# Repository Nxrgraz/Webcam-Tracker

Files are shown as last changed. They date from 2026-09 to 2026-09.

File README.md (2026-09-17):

# AI Pan Tilt Face Tracker

A real time two axis vision tracking system that detects and follows a specific face using a custom YOLO model, C++, OpenCV, model predictive control, and Arduino controlled pan and tilt servos.
## Demo

[Watch the full face tracking demo](demo/tracker_demo.mp4)

The system combines computer vision, target motion estimation, feedback control, and embedded hardware to keep a detected face near the center of the camera frame while reducing overshoot, jitter, and unnecessary servo movement.

## Overview

A webcam continuously captures video while a custom YOLO ONNX model detects the target face.

The software measures the target's position relative to the center of the image and estimates its movement across the frame. Independent predictive controllers for the pan and tilt axes then determine how the camera should move.

Instead of reacting only to the current image error, the controller predicts how the target and camera are expected to move over the next several control steps.

The resulting commands are transmitted over serial to an Arduino controlling the two servo motors.

## System Pipeline

```text
Webcam
   |
   v
Camera Frame
   |
   v
Image Preprocessing and Letterboxing
   |
   v
Custom YOLO Face Detector
   |
   v
Non Maximum Suppression
   |
   v
Target Selection and Tracking
   |
   v
Face Position Smoothing
   |
   v
Image Error Calculation
   |
   v
Target Motion Observer
   |
   +----------------------+
   |                      |
   v                      v
Target Velocity      Servo Motion Model
   |                      |
   +-----------+----------+
               |
               v
       Future Motion Prediction
               |
        +------+------+
        |             |
        v             v
     Pan MPC       Tilt MPC
        |             |
        +------+------+
               |
               v
     Velocity and Acceleration
             Limits
               |
               v
       Servo Angle Commands
               |
               v
            Arduino
          /         \
         v           v
    Pan Servo    Tilt Servo
```

## Features

### Custom Face Detection

The tracker uses a custom YOLO model exported to ONNX and executed through OpenCV DNN.

The detector runs on a letterboxed 640 × 640 image while preserving the original camera aspect ratio.

Detections below the confidence threshold are rejected and Non Maximum Suppression is used to remove overlapping detections.

### Target Association

When tracking begins, the highest confidence detection is selected.

Once a target has been established, subsequent detections are compared with the previous smoothed target position. The closest detection is selected to reduce unnecessary switching between detected objects.

### Target Position Smoothing

Raw bounding box positions from the detector can change slightly even when the target is stationary.

An exponential smoothing filter is applied to the detected face center before the position is used by the controller.

This reduces camera movement caused by small detection fluctuations.

### Predictive Motion Estimation

The tracker estimates the image velocity of the target from consecutive measurements.

The observer also estimates how much apparent image motion is being produced by movement of the camera itself.

Conceptually,

```text
Target Image Velocity =
Observed Image Velocity
-
Camera Induced Image Velocity
```

This helps distinguish actual target motion from image movement caused by the pan and tilt servos.

### Model Predictive Control

Automatic tracking uses independent predictive controllers for the pan and tilt axes.

For each control cycle, the controller evaluates a range of possible servo velocity commands and simulates their effect over a future prediction horizon.

Each candidate command is scored using a cost function that considers

```text
Tracking error
Control effort
Change in control command
Terminal tracking error
```

The command producing the lowest predicted cost is selected.

This allows the system to react not only to where the target currently is, but also to where it is moving.

### Servo Dynamics Model

The predictive controller contains a simplified first order model of each servo axis.

The model includes

```text
Servo response time
Command gain
Estimated control delay
Pixels of image movement per degree of camera rotation
Maximum servo velocity
Maximum servo acceleration
```

Pan and tilt are modeled separately because the mechanical response of the two axes is different.

The current model parameters are initial estimates and are intended to be refined using experimental measurements.

### Delay Compensation

Camera processing, neural network inference, serial communication, and servo movement introduce delay.

The controller maintains a queue of previous commands to approximate this delay when predicting future system behavior.

This prevents the controller from assuming that a newly issued servo command affects the camera immediately.

### Predictive Tracking Activation

Tracking does not depend only on position error.

The system also considers estimated target velocity.

If a target begins moving quickly, tracking can activate before the target moves far from the center of the image.

This improves response to moving targets compared with a purely position based dead zone.

### Tracking Hysteresis

Different thresholds are used for starting and stopping movement.

For example, the pan axis requires a larger error to begin tracking than it requires to stop tracking.

This prevents rapid switching between moving and stopping when the target is close to the center of the frame.

### Stationary Hold

When the target remains close to the image center and nearly motionless for several consecutive control cycles, the tracker enters a stationary hold state.

During stationary hold

```text
Pan velocity is set to zero
Tilt velocity is set to zero
Predictive velocity states are reset
Servo targets are synchronized with the physical servo commands
```

The hold is released immediately when the target moves far enough or fast enough.

This reduces continuous servo hunting caused by small camera and detector fluctuations.

### Motion Constraints

Servo motion is limited by both velocity and acceleration constraints.

Current software limits are approximately

```text
Maximum velocity:      18 degrees per second
Maximum acceleration:  45 degrees per second squared
```

These limits help produce smoother physical movement and prevent aggressive controller commands.

### Servo Safety Limits

Software limits prevent the mechanism from commanding unsafe angles.

```text
Pan:   15 to 165 degrees
Tilt:  60 to 120 degrees
```

### Target Loss Handling

When the face is temporarily lost, servo velocities are gradually reduced instead of stopping abruptly.

After the target has been missing for several frames, the tracking and prediction states are reset.

This prevents stale target information from affecting the next detection.

### Manual Control

The tracker can be switched between automatic MPC tracking and manual control.

```text
M     Toggle automatic and manual mode

W     Tilt camera up
S     Tilt camera down
A     Pan camera left
D     Pan camera right

R     Smoothly return both axes to center

Q     Quit
ESC   Quit
```

### Smooth Center Reset

Pressing `R` disables automatic tracking and gradually returns both axes to

```text
Pan:  90 degrees
Tilt: 90 degrees
```

rather than immediately snapping the servos to their center positions.

## Visual Debugging

The OpenCV display includes

```text
Detected face bounding box
Detection confidence
Raw face center
Smoothed face center
Camera frame center
Tracking dead zone
Predicted future target position
Current pan angle
Current tilt angle
Number of detections
Current operating mode
```

The predicted target location is displayed separately from the current target location so the motion observer can be inspected visually.

## Controller Debug Output

The application also prints controller information to the terminal, including

```text
Pan target angle
Pan angle sent to Arduino
Tilt target angle
Tilt angle sent to Arduino
Horizontal image error
Vertical image error
Estimated target velocity
Estimated camera velocity
MPC pan command
MPC tilt command
Stationary hold status
```

This information can be recorded during testing and used to tune the predictive model.

## Hardware

The system is designed around

```text
Webcam
Arduino
Two axis pan tilt mechanism
Two servo motors
Computer running the C++ vision and control application
```

The computer performs neural network inference and predictive control while the Arduino receives pan and tilt angle commands and drives the physical servos.

## Software

The project uses

```text
C++
OpenCV
OpenCV DNN
ONNX
YOLO
Serial communication
Arduino
Model Predictive Control
```

## Communication

The computer communicates with the Arduino through a serial connection at

```text
115200 baud
```

Servo commands are transmitted using the format

```text
panAngle,tiltAngle
```

For example

```text
92.35,87.72
```

The controller avoids transmitting another command when both servo angles have changed by less than a small threshold.

## Current Control Configuration

The controller currently runs at approximately 20 Hz.

The MPC prediction horizon contains 10 control steps, corresponding to roughly 0.5 seconds of predicted motion.

Pan and tilt use separate dynamic models and delay estimates.

These values are currently starting estimates rather than experimentally identified plant parameters.

## Current Development Direction

The next major control improvement is experimental system identification.

Future testing can be used to measure

```text
Actual servo response time
Pan and tilt command delay
Pixels per degree of camera movement
Servo command gain
Response differences across servo angles
```

These measurements can then replace the initial model estimates used by the predictive controller.

Additional future improvements include

```text
Automatic controller parameter identification
Performance logging and plotting
Quantitative tracking error evaluation
Improved target reacquisition
Hardware specific servo calibration
Higher performance inference
More advanced coupled pan and tilt control
```

## Project Goal

The goal of this project is not simply to move a webcam toward a detected face.

It is to explore how computer vision, machine learning, state estimation, feedback control, and embedded hardware can be integrated into a complete real time robotic tracking system.

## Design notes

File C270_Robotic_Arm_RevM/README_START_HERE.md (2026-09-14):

# C270 robotic arm Revision M

Revision M enlarges the cap opening to **27 × 15 mm**, provides direct access to the original servo shaft screws, and turns the webcam mount so the upper servo aims the camera up and down. The arm is now 10 mm thick to reduce sideways flex.

**Print three updated parts: the arm, cap, and webcam cradle. Reuse the Revision L base.** The base STL in this package is unchanged. Revision M cap holes use a new **34 × 17 mm** pattern and require the matching Revision M arm.

| File in Printable_Parts | Quantity | Action |
| --- | --- | --- |
| CurvedArm_SG90_TiltHolder.stl | 1 | Print the new thicker arm with screw access and cable tie tabs |
| SG90_RetainingCap.stl | 1 | Print the 27 × 15 mm opening and matching screw pattern |
| Logitech_C270_ScrewlessCradle.stl | 1 | Print the new side-mounted cradle for actual camera tilt |
| PanServo_StabilityBase.stl | 1 total | Reuse your existing Revision L base |

Print individual STLs. The STEP assemblies show placement and can be imported into SolidWorks; they are not files to print as a single object. The servos and camera in the full assembly are visualization references.

## Stability requirement

**Secure the gray base to a rigid work surface using its four M4 mounting holes.** The analysis does not support claiming that the lightweight base will resist cable pull while free-standing. The revised arm is stiffer, but printed-part flex, servo backlash and shaft-bearing compliance still require a physical check.

## Read before assembly

- `Documentation/Assembly_and_Printing_Guide.md` explains the screws, assembly order and what to print.
- `Documentation/Wiring_and_Motion.md` explains both USB connections, servo power, cable slack and travel limits.
- `Documentation/Engineering_Check.md` gives the assumptions, torque calculation and tipping calculation.
- `Documentation/CAD_and_Engineering_Results.json` contains the computed measurements and individual check results.
- `Software/Camera_RevM.cpp` and `Camera_RevM.exe` provide a separate tracker build with narrower commands and slower outgoing motion. Read the wiring guide before using it; it has not been run against hardware.

The previous Word guides remain with their older revisions. This revision's guides supersede their cap, cradle, screw-access, axis and stability instructions.

## Main dimensions

- Rectangular cap opening: 27 × 15 mm; this adds 5 mm to the former 22 mm side.
- Cap outer face: 42 × 26 mm; face thickness: 3 mm. Ear retaining pads extend 2.6 mm behind that face.
- Cap holes: 2.4 mm clearance; centers: 34 × 17 mm. Holder pilots: 1.8 mm.
- Original shaft-screw access: 6.4 mm diameter in the arm and cradle.
- Printed horn-screw seats: 1.2 mm material thickness after recessing.
- Arm ribbon: 14 mm wide, 10 mm thick; nominal 80 mm end-center spacing.
- Tilt: rotation about the upper servo's Y shaft; modeled movement −45° to +45°.
- Pan: rotation about vertical Z. These are two independent aiming rotations.

The screw-access changes address the blocked shaft-screw path found in the model. Actual screw head size, thread and under-head length have not been measured from your hardware. Compare them with the fastener table before tightening.

## Rebuilding the CAD

The `Source` folder contains the generator and build/verification script. Install the dependencies in an isolated Python environment, then run `python build_verify_revM.py` from that folder. The script regenerates the CAD, previews and numerical results in this revision folder; the written guides are maintained separately. Generated STEP files contain solids rather than a native SolidWorks feature history.

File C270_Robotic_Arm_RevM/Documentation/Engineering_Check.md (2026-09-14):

# Revision M engineering check

The geometry supports two independent camera aiming rotations and provides access to the shaft screws. The tipping calculation requires the base to be anchored. These checks establish geometric clearance and stated load estimates; they do not establish the strength of an unknown print or servo clone.

## Geometry and movement

The camera looks along +X at neutral. The pan shaft is vertical Z and the tilt shaft is Y. For pan p and tilt t, the viewing direction is `(cos(p)cos(t), sin(p)cos(t), -sin(t))`. At tilt −45°, 0° and +45°, the vertical component is respectively +0.7071, 0 and −0.7071. The upper joint therefore changes camera elevation rather than rolling the image.

The CAD checks sample tilt every 5° from −45° to +45°, checking the cradle, camera, clip, rotating horn and a straight rear cable proxy against the fixed parts. Those checks pass. The minimum sampled camera/cradle-to-fixed clearance is about 2.17 mm. Rotation about Y preserves every point's Y coordinate, and the moving camera/cradle assembly has at least 2 mm of axial separation from the upper fixed parts. A separate radial bounding check keeps it above the base throughout the motion, providing clearance bounds between the sampled angles as well. The flexible cable loops and actual molded connectors are not represented by those bounds.

The cap opening is 27 × 15 mm. Moving its screws to 34 × 17 mm centers retains at least 2.3 mm of material between the opening and the hole edges using a conservative horizontal measurement. A 6 mm under-head cap screw crosses 3 mm of cap and engages 3 mm of holder pilot. The modeled pilot surroundings contain material over that engagement length.

The arm and cradle have 6.4 mm center access openings. Original shaft screws seat on the original servo horns, so printed material does not consume their reach. Separate recessed horn screw seats leave 1.2 mm of print. Actual screw threads, heads, lengths and horn hole positions must be checked against the hardware.

## Tilt holding torque

For a mass m at perpendicular radius r from the tilt shaft, the maximum gravitational torque is `m g r`. In the customary kg·cm servo unit, use mass in kilograms multiplied by radius in centimetres.

The camera plus fixed clip is assigned the supplied 75 g total mass. Rather than guessing its exact center of mass, the calculation allows that mass center anywhere inside the camera/clip CAD envelope. Its maximum radial distance from Y is 49.92 mm. Printed cradle mass uses its CAD volume and a maximum effective density of 1.27 g/cm³.

| Quantity | Result |
| --- | --- |
| Camera and cradle gravity bound | 0.381 kg·cm |
| Gravity allowance for motion, chosen factor | 1.5 × |
| Assumed residual cable drag | 0.20 N at a 60 mm radius |
| Cable torque | 0.122 kg·cm |
| Estimated combined design demand | 1.5 × 0.381 + 0.122 = **0.694 kg·cm** |
| TowerPro SG90 published stall torque at 4.8 V | 1.8 kg·cm |
| Published stall torque divided by estimated demand | 2.59 |

The 0.20 N cable drag and 1.5 motion multiplier are design assumptions, not measurements or a simulation of the actual acceleration. A snag or fast reversal can exceed them. The published stall rating is not a continuous operating rating or a guarantee of stiffness. Actual servo type, voltage, temperature, wear and gear backlash affect holding performance. Check the powered assembly for sag and heating; do not describe this estimate as a proof that the camera can never droop.

The original [TowerPro SG90 specification](https://towerpro.com.tw/product/sg90-7/) is the source for the 1.8 kg·cm stall figure. It is a reference for a genuine TowerPro unit, not identification of the supplied hardware.

## Base tipping

For component masses m_i and positions r_i, the combined center of mass is `r_COM = sum(m_i r_i) / sum(m_i)`. On a circular base, a gravity-only stability margin is `R - horizontal_distance(r_COM, base_center)`.

The printed-part analysis samples effective density from 0.434 to 1.27 g/cm³ independently for each part. This deliberately broad range spans a light print through a solid plastic part; it is not a conversion from the slicer's infill percentage. The camera center of mass is allowed anywhere in its full envelope. The servos are assigned 9 g each and the horns 2 g each. Component centers come from CAD, with each moving part transformed through the tilt range.

To account for the rounded bottom edge, usable base support radius is taken as 68 mm rather than the nominal 70 mm. The worst sampled combination gives:

| Quantity | Conservative sampled result |
| --- | --- |
| Total moving and fixed assembly mass | 154.20 g |
| Horizontal center-of-mass radius | 63.78 mm |
| Remaining edge margin | **4.22 mm** |
| Restoring moment `M = total_mass × g × margin` | **0.00638 N·m** |
| Horizontal force at 180 mm height that equals that restoring moment | **0.0355 N** |

This is an intentionally conservative corner-of-envelope case, not a prediction of the exact physical center of mass. It nevertheless shows why a blanket promise of free-standing stability would be unjustified. Even when a real sample is better balanced, a cable pull can dominate the small restoring moment.

**Fasten the base to a rigid work surface with all four M4 holes, and anchor the stationary cable bundle beside it.** The holes form a 70.711 mm square. Use suitable washers and nuts and confirm the printed recesses are sound. A 1 N horizontal pull at 180 mm height creates 0.18 N·m; allowing twice that moment corresponds to approximately 5.1 N of additional force across a 70.711 mm bolt-row spacing. This estimates the anchor reaction, not a certified allowable load for the print, washers or work surface. A lightweight loose board can tip with the assembly and is not equivalent to a secured work surface.

## Arm flex

The ribbon thickness increases from 6 to 10 mm while its nominal width remains 14 mm. For the same homogeneous material, weak-direction rectangular-section inertia is `I = b t³ / 12`:

- Previous nominal section: 252 mm⁴.
- Revised nominal section: 1166.7 mm⁴.
- Ratio: 4.63.

This is a section comparison, not a claim that the complete printed arm is exactly 4.63 times stiffer. Curvature, screw access cutouts, layer orientation, infill, local stress concentrations and joints change the real result. The calculation does not include servo shaft/bearing deflection or horn compliance. Anchoring prevents base movement; a load test is still needed to check arm and joint sag.

## Acceptance checks on the real assembly

Measure the relevant servo feature before printing the new cap. Weigh the printed parts and record the material and settings. With the base anchored, support the camera during initial power-up and test one axis at a time near neutral. Increase travel gradually, confirming there is no wire tension, rubbing, case movement or loss of level at neutral. Do not force an unpowered geared servo through its travel. Observe whether the powered camera sags or the servos heat up under sustained load. Confirm physical travel limits before tracking.

The supplied tracker build reduces commands to the logical range 45–135 and at most one degree per 33 ms. Those limits reduce commanded motion; they do not measure cable force, guarantee physical servo angle or prevent droop after power loss.

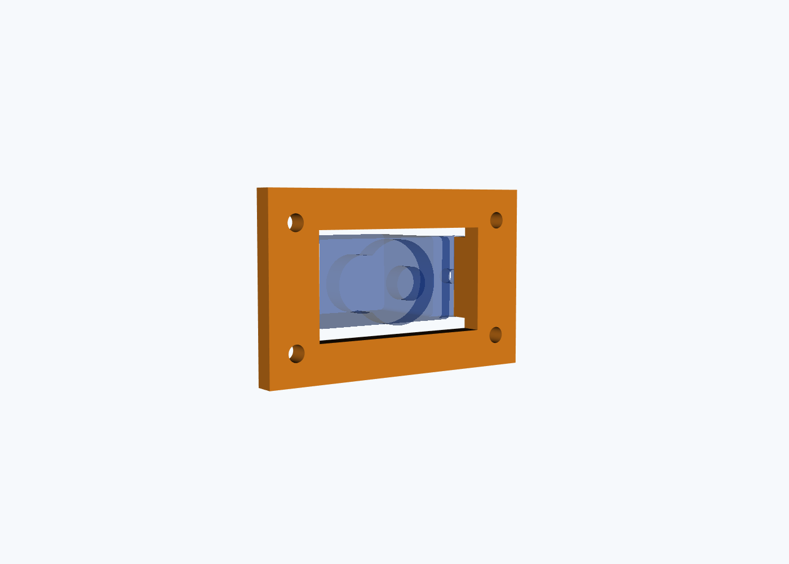
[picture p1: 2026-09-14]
C270_Robotic_Arm_RevM/Renders/07_SG90_RetainingCap_Rectangular_Clearance.png

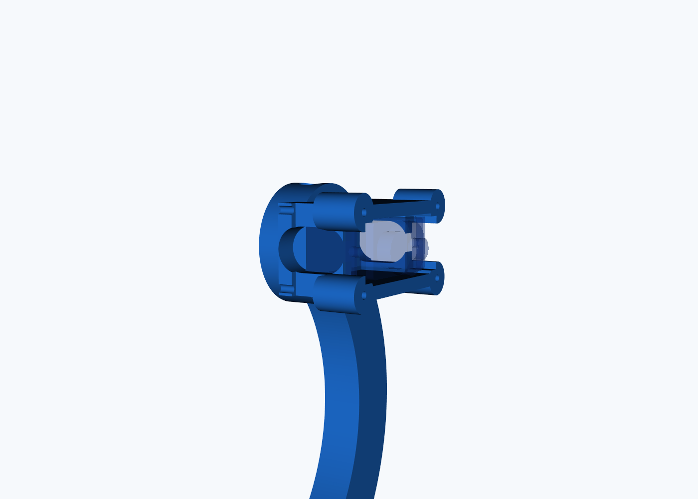
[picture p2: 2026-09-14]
C270_Robotic_Arm_RevM/Renders/05_Arm_Side_Cable_Exit.png

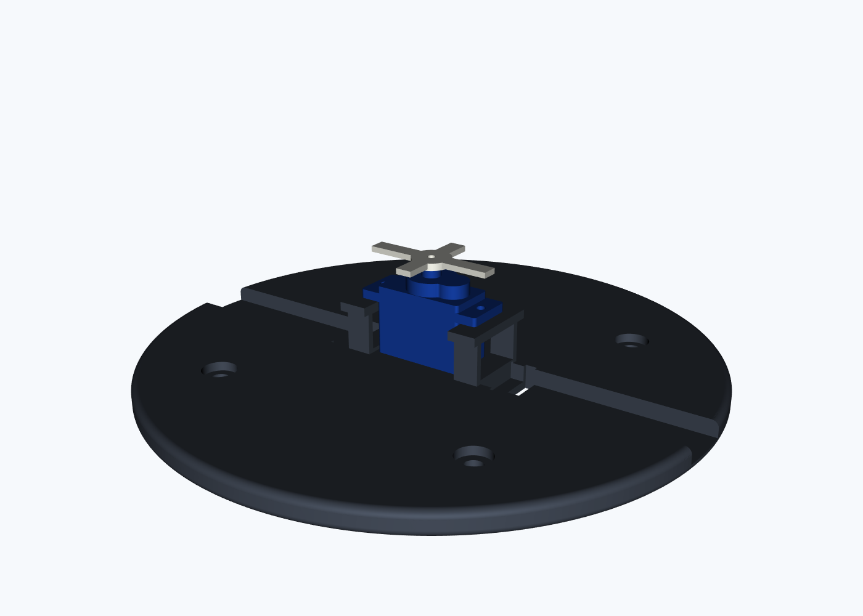
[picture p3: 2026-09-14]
C270_Robotic_Arm_RevM/Renders/04_Pan_Servo_Stability_Base.png

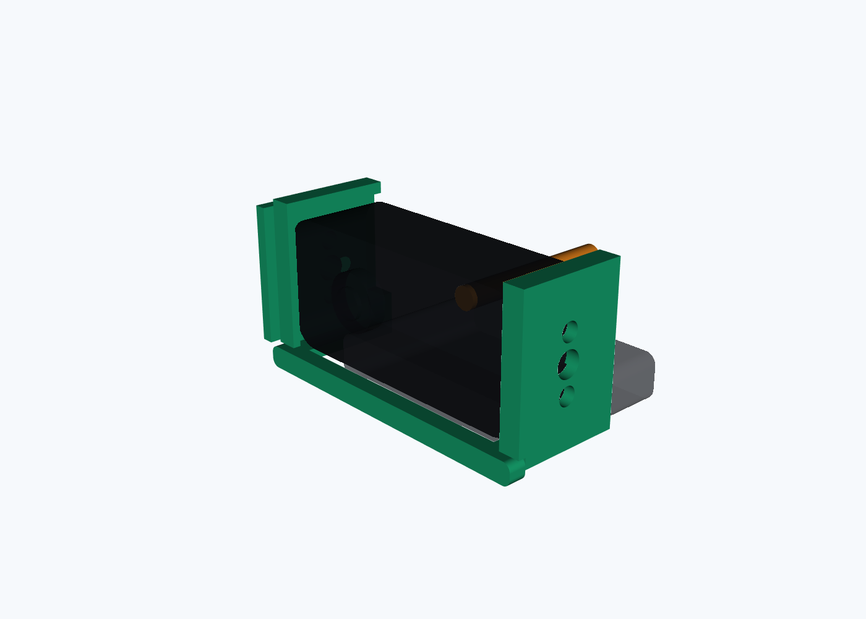
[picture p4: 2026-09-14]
C270_Robotic_Arm_RevM/Renders/06_Screwless_C270_Cradle.png

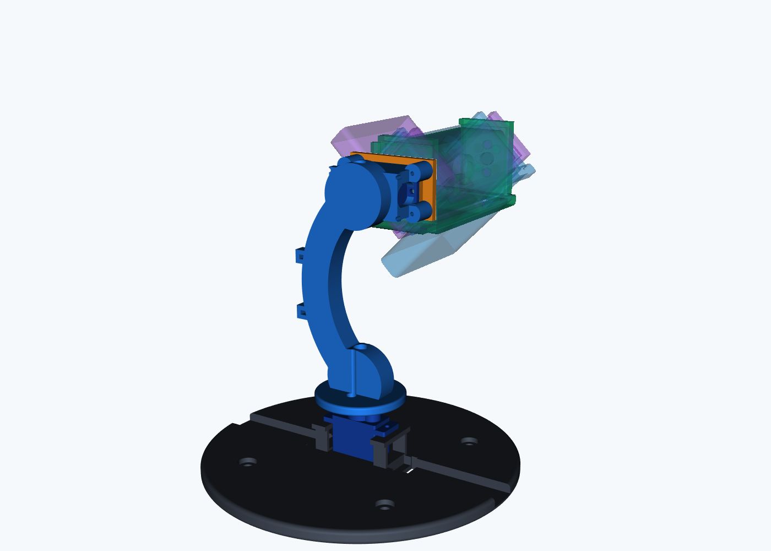
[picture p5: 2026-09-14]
C270_Robotic_Arm_RevM/Renders/03_Tilt_Range_Minus45_to_Plus45.png

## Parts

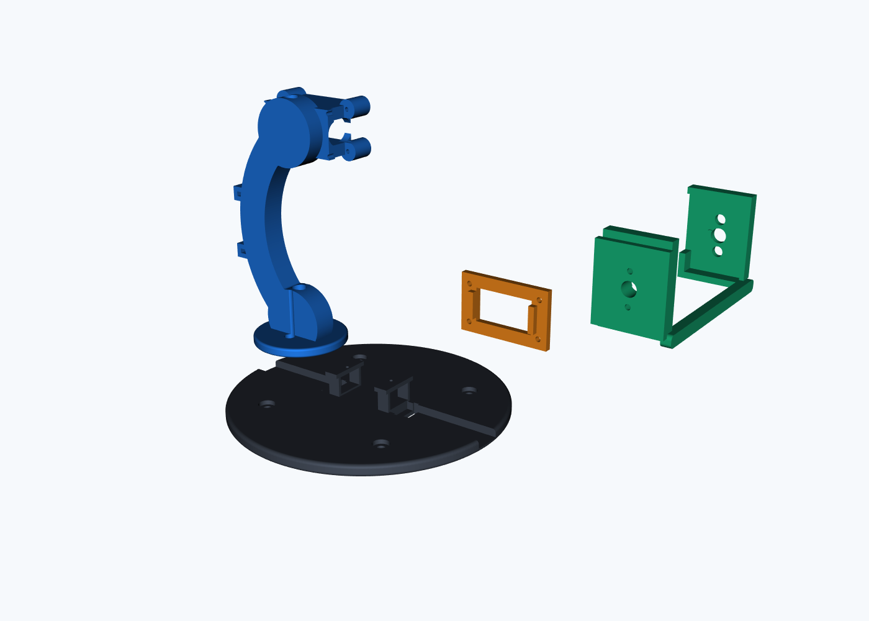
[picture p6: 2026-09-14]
C270_Robotic_Arm_RevM/Renders/02_Exploded_Printable_Parts.png

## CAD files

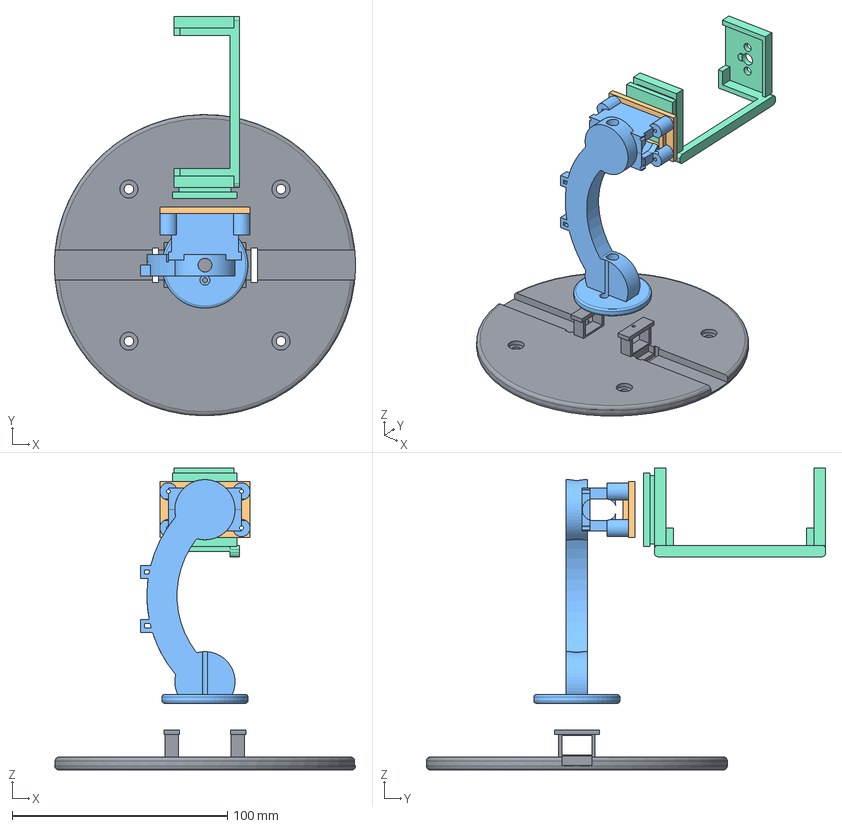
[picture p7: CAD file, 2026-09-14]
C270_Robotic_Arm_RevM/Assemblies/C270_PanTilt_Printable_Assembly.step
140.0 x 185.7 x 140.4 mm
PanServo_StabilityBase
CurvedArm_SG90_TiltHolder
SG90_RetainingCap
Logitech_C270_ScrewlessCradle

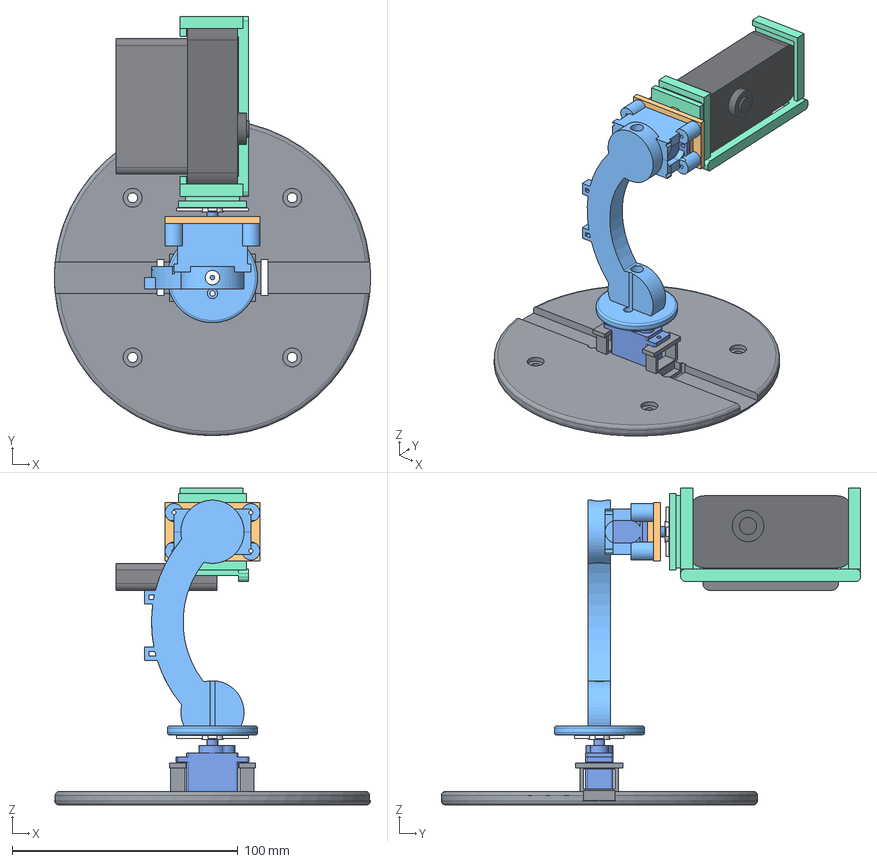
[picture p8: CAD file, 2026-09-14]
C270_Robotic_Arm_RevM/Assemblies/C270_PanTilt_Full_Assembly_With_Servos.step
140.0 x 185.7 x 140.4 mm
PanServo_StabilityBase
CurvedArm_SG90_TiltHolder
SG90_RetainingCap
Logitech_C270_ScrewlessCradle
SG90_Pan_Body
SG90_Pan_Horn
SG90_Tilt_Body
SG90_Tilt_Horn
C270_Webcam_Body
C270_Fixed_Clip

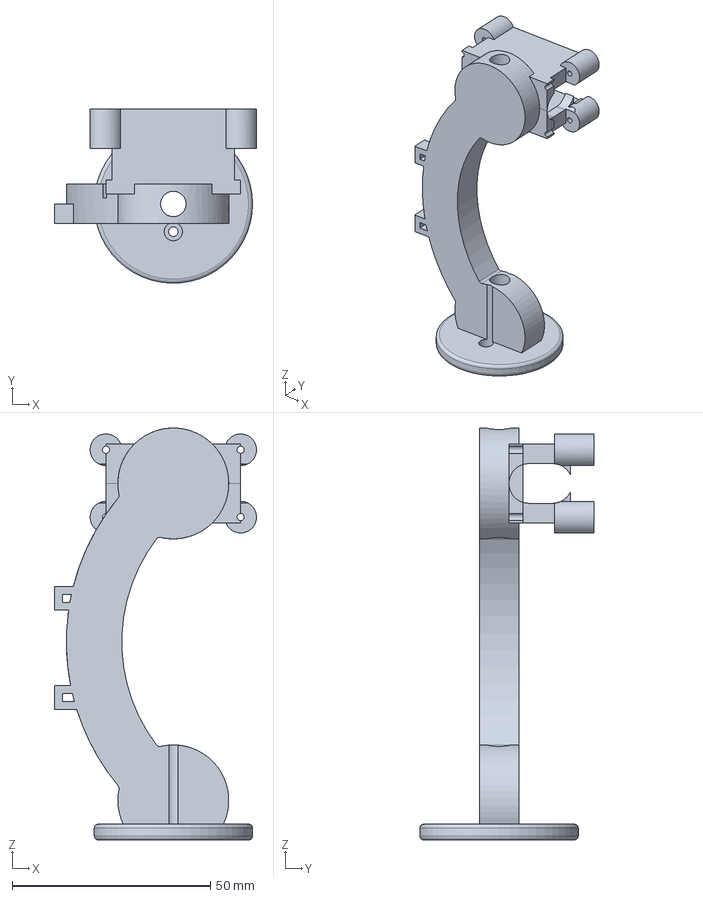
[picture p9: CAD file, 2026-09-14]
C270_Robotic_Arm_RevM/Printable_Parts/CurvedArm_SG90_TiltHolder.step
51.0 x 44.0 x 104.0 mm

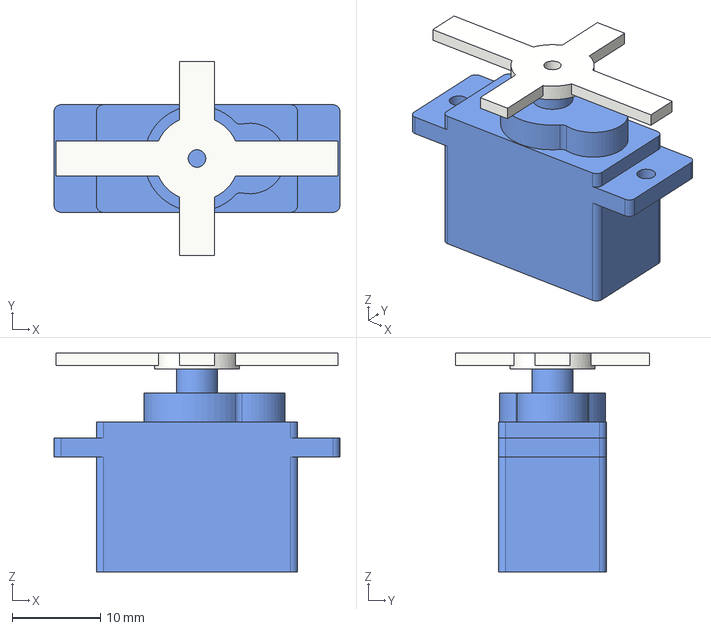
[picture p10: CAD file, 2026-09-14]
C270_Robotic_Arm_RevM/Reference_Models/SG90_Visual_Reference.step
32.4 x 22.0 x 24.8 mm
SG90_Body
SG90_Cross_Horn

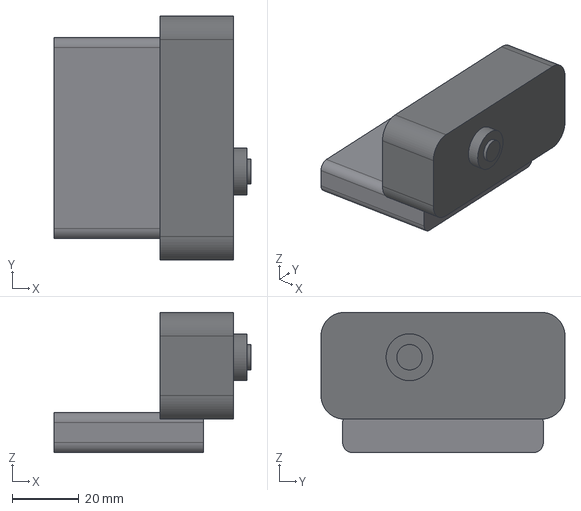
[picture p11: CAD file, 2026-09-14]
C270_Robotic_Arm_RevM/Reference_Models/Logitech_C270_Visual_Reference.step
58.8 x 72.9 x 41.9 mm
C270_Body
C270_Fixed_Clip

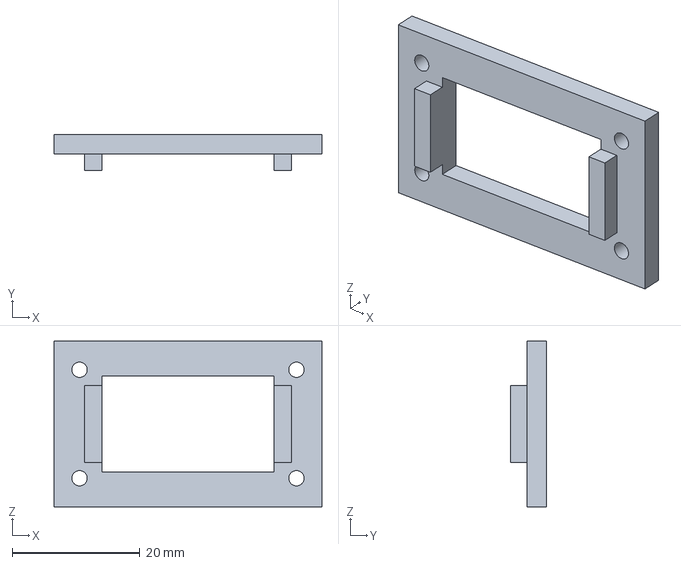
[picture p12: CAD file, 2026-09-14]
C270_Robotic_Arm_RevM/Printable_Parts/SG90_RetainingCap.step
42.0 x 5.60 x 26.0 mm

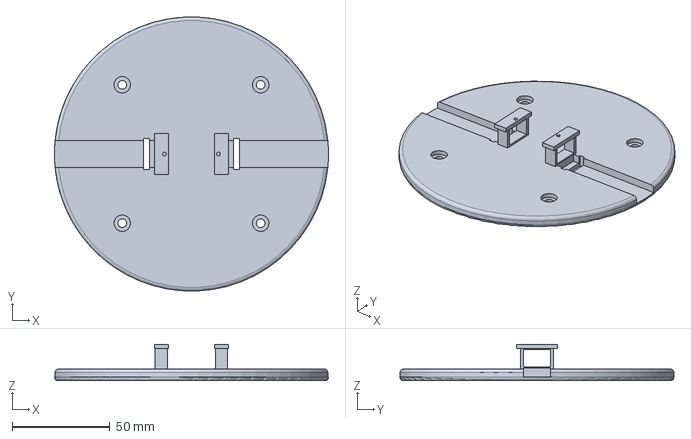
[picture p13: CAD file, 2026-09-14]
C270_Robotic_Arm_RevM/Printable_Parts/PanServo_StabilityBase.step
140.0 x 139.9 x 18.6 mm

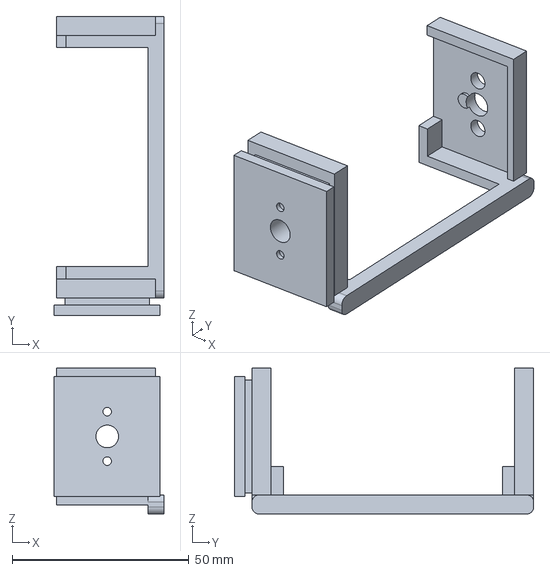
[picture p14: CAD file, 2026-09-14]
C270_Robotic_Arm_RevM/Printable_Parts/Logitech_C270_ScrewlessCradle.step
31.0 x 84.7 x 41.3 mm

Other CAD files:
C270_Robotic_Arm_RevM/Printable_Parts/CurvedArm_SG90_TiltHolder.stl
C270_Robotic_Arm_RevM/Printable_Parts/Logitech_C270_ScrewlessCradle.stl
C270_Robotic_Arm_RevM/Printable_Parts/PanServo_StabilityBase.stl
C270_Robotic_Arm_RevM/Printable_Parts/SG90_RetainingCap.stl

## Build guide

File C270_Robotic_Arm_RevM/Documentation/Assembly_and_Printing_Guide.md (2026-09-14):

# Revision M assembly and printing guide

Assemble with the camera removed and the servos unpowered except when centering them. The camera inserts last so it cannot obstruct screwdriver access across the cradle.

## Screws and their jobs

| Connection | Fastener and quantity | How it reaches |
| --- | --- | --- |
| Each servo output shaft to its original plastic horn | The original shaft screw supplied with that servo; 1 each | Its head passes through the 6.4 mm access opening and seats directly on the horn. Printed plastic adds no thickness under this screw head. |
| Printed arm to pan horn | Two approximately 2 mm diameter self-tapping horn screws, nominally 4 mm under the head | Recesses leave 1.2 mm of print, followed by the horn. Use the two holes at Y = ±7 mm. |
| Printed cradle to tilt horn | Two approximately 2 mm diameter self-tapping horn screws, nominally 4 mm under the head | Recesses leave 1.2 mm of print. Use the two holes at Z = ±7 mm, with camera absent. |
| Orange cap to blue holder | Four M2-class self-tapping screws, 6 mm under the head | 3 mm of cap plus 3 mm into the printed 1.8 mm pilot. Pattern is 34 × 17 mm. |
| Pan servo ears to base | Two approximately 2 mm diameter self-tapping servo mounting screws | Original ear spacing is 27.5 mm. Select length from the actual ear thickness plus about 3 mm engagement into the printed base pilots. |
| Base to rigid work surface | Four M4 bolts, washers and nuts appropriate to the work surface | Existing 4.4 mm through-holes; choose length from the actual surface thickness, base thickness, washers and nut. |

The small screw into the servo shaft is not interchangeable with the screws that attach the horn or servo ears. Do not use nails, force an M2 machine screw into an unknown shaft thread, or fit an arbitrarily longer shaft screw: it can bottom out inside the servo.

The model provides clearance for a shaft-screw head up to approximately 6 mm and a driver tip smaller than the 6.4 mm opening. Measure the actual head before use. The 4 mm horn screw is a starting selection for the modeled 1.4 mm horn blade, not a claim that every SG90 horn has that thickness or hole pattern. A 4 mm screw through the 1.2 mm print and modeled 0.2 mm gap leaves 2.6 mm reach into and through the horn. Check the back of the actual horn for tip clearance before fitting it to the servo. The two horn hole centers must match the actual horn's holes at ±7 mm; mark or adapt the plastic horn off the servo if they do not match.

## Assembly order

1. Reuse the base and check that its side windows and grooves are clear. Fasten it to a rigid work surface using the four M4 holes. Their centers are at X/Y = ±35.355 mm: a 70.711 mm square. Place washers beneath the mounting screw heads. The modeled counterbore is 8.4 mm diameter and 2.2 mm deep, so select washers that fit it or seat on the surrounding flat surface.
2. Seat the pan servo on the base with its shaft upward. Pass its wire through the matching SIDE window, lay it in that side's groove, and fasten the servo ears. Screw length should give about 3 mm of engagement after passing the actual ear; check that the screw does not bottom in the pilot.
3. With the horn detached from the servo, fasten the printed arm to the pan horn using the two recessed mounting holes. Do this before installing the tilt servo. Use a short driver/bit for the pad recesses. The center access opening remains empty at this stage.
4. Center the pan servo electrically, power it off, then seat the horn/arm assembly on its spline. Insert the servo's original center screw through the arm's enlarged access channel. The screw head must seat on the original horn below the printed arm. Tighten gently.
5. Route the tilt servo's own cable through either enlarged SIDE opening in the upper holder and slide the servo into its cage. The shaft points along Y. Ensure the wire is clear of the ear slots and cap contact pads.
6. Fit the Revision M cap over the output side and install four 6 mm M2-class self-tapping screws into the matching Revision M holder. The 27 × 15 mm opening surrounds the raised servo portion; two rear pads retain its ears. Do not use the old 27.7 × 15 mm cap pattern. Check that the servo seats and is held without crushing its case.
7. With the webcam absent, attach the corrected cradle to the original tilt horn using its two recessed holes. Center the tilt servo electrically, power it off, and put the horn/cradle on the spline with the camera position level.
8. Insert the tilt servo's original shaft screw through the access holes across the empty cradle. It seats on the horn, below the print. Check that both horn screws and the shaft screw are secure and that their tips do not contact the servo case.
9. Gently install the webcam. The shelves carry the body; side cheeks and corner returns retain it. Its fixed clip hangs through the open underside. The split low rear barriers help prevent backward movement while leaving the central rear opening clear.
10. Route the webcam USB lead straight out of the back, then form a loose loop toward the arm. Keep the full USB plug outside the holder; use the new tie tabs for the external cable bundle. Follow the wiring guide before applying power.
11. Support the webcam by hand during the first powered test. Start near neutral, move one axis at a time, and gradually check both directions. Stop for wire tension, sag, case movement, rubbing, buzzing, or unexpected direction. Measure the real tilt angle before allowing the full ±45° CAD travel.

The original shaft screw holds the horn to the spline. The separate horn screws keep the printed part from rotating on the horn. Both connections are necessary.

## Printing

Print one new arm, one new cap and one new cradle. The base is unchanged from Revision L. Use millimetres and 100% model scale.

| Part | Orientation to discuss with the print operator | Suggested starting settings |
| --- | --- | --- |
| Arm and holder | Broad curved side down, with the curved ribbon in the bed plane | 0.20 mm layers, 5–6 walls, about 50% infill; supports only where the holder/pad creates unsupported starts |
| Retaining cap | Flat outer 42 × 26 mm face down; rear ear pads face upward | 0.20 mm layers, 4 walls or solid infill; no supports in the rectangular opening or screw holes |
| Corrected webcam cradle | Broad servo mounting face down; inspect the opposite cheek and corner returns in the slicer | 0.20 mm layers, 4 walls, 35–45% infill; brim as needed and removable supports under unsupported starts/overhangs |
| Existing base, if a replacement is needed | Circular underside down | 0.20 mm layers, 4 walls, 35–45% infill; keep both side cable ports and grooves clear |

The print operator should decide final supports and settings from the slicer preview. The cradle has overhangs and may require supports inside it; this has not been sliced on your printer. Remove supports fully before inserting the camera or screws. PLA/PLA+ favors stiffness for indoor use; PETG is another option for the flexible cradle, but either material needs a real fit and load test. Do not force the camera against a rigid or poorly printed lip.

The calculated mass bounds are deliberately broad. Weigh the finished parts: nominal infill percentage alone does not give an accurate mass or stiffness.

## Before another full print run

Check the cap opening against the actual servo's raised feature, and check the screw head against the access opening. Print the small cap first if the hardware dimensions are uncertain. The cap cannot be fastened to the old arm because its hole pattern has changed. Do not scale the whole model to fix a local fit problem; that changes every screw position.

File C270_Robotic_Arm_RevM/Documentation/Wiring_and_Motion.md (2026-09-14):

# Revision M wiring and motion

Keep the Arduino on the stationary work surface next to the anchored base. No Arduino model or mounting-hole pattern has been confirmed, so this revision does not add a board mount. Both servos move the mechanism; neither USB connection should carry its mechanical load.

## Electrical connections

| Connection | Destination |
| --- | --- |
| Webcam USB cable | Computer USB port |
| Arduino USB cable | Computer USB port for serial commands and Arduino power |
| Both servo red wires | Positive terminal of a regulated external servo supply matched to the actual servos |
| Both servo brown/black wires | External supply ground |
| Arduino GND | The same external supply ground |
| Pan servo signal wire | The Arduino output pin named for PAN in your firmware |
| Tilt servo signal wire | The Arduino output pin named for TILT in your firmware |

Verify wire functions on the actual servo. Brown/black ground, red positive and orange/yellow signal are common SG90 colors. Do not run the servo current through an Arduino I/O pin. With the Arduino powered by USB, keep the external servo positive rail separate from the Arduino 5 V pin unless a specific power-sharing design is provided.

A regulated 5 V supply is a candidate only if the labels/specifications of your actual servos permit it. Size the supply for both motors' simultaneous current, including startup/stall; exact clone current has not been measured. TowerPro's official SG90 page lists 4.8 V operation and its manufacturer response permits 4.8–6 V, but this does not identify your specific servo clone.

Arduino advises using an external servo supply when board power is insufficient and joining the Arduino and supply grounds. See [Arduino servo troubleshooting](https://support.arduino.cc/hc/en-us/articles/360017053760-Troubleshoot-servo-motors) and [TowerPro SG90 specifications](https://towerpro.com.tw/product/sg90-7/).

## Physical cable routing

1. The pan servo lead exits from its SIDE and lies in the matching base groove. Keep it below the rotating horn and arm pad.
2. The tilt servo lead exits a SIDE window in the upper holder. It moves with pan but does not need to rotate with the camera cradle.
3. The webcam cable exits the open BACK of the cradle. Leave the first section free of the rear retention corners and the clip. Its six-millimetre-diameter, 42 mm straight exit envelope was checked in CAD; the actual molded strain relief and the rest of the cable still need a physical check.
4. Make a generous U-shaped service loop between the camera and the arm so tilt can move in both directions without pulling the connector. Then tie the external bundle loosely to the two new arm tabs. Their 4 × 2 mm slots accept narrow zip ties; they are tie slots, not holes for USB plugs.
5. Leave another loop between the rotating arm and the stationary base/Arduino. It must accommodate the full permitted pan movement. Anchor the stationary cable bundle to the work surface close to the base so pulling a computer cable does not pull the camera directly.
6. Move to all four combinations of minimum/maximum pan and tilt. The loops must remain loose, clear of horns and screw heads, and above sharp edges. The flexible loops are not fully represented by the rigid CAD cable proxy.

Do not thread a large molded USB connector through the servo cage, wind wiring around either shaft, or allow unlimited pan. Match the cable's bend radius to its actual construction and leave additional slack rather than forcing a tight bend.

## What the two axes now do

At neutral, the camera looks along CAD +X. Pan rotates around vertical Z, aiming left/right. Tilt rotates around the upper servo's Y shaft, which runs across the camera's width, aiming up/down. This gives two independent aiming angles; it is not a planar XY translation mechanism.

The older cradle pointed the lens parallel to the Y shaft, which would roll the image. The Revision M cradle corrects that orientation.

With pan angle p and tilt angle t measured from neutral, the camera viewing direction is

`(cos(p) cos(t), sin(p) cos(t), -sin(t))`.

The sign of a real servo's movement depends on horn placement and firmware. Check it at low travel before enabling tracking.

## Controller limits and first test

The existing `Camera.cpp` sends `pan,tilt` followed by a newline at 115200 baud. It currently clamps both requested angles to 0–180. That is broader than the travel checked for this mechanism.

The separate `Software/Camera_RevM.cpp` and compiled `Camera_RevM.exe` apply a starting logical range of **45–135**, with logical neutral at 90, and limit outgoing movement to one degree per axis at intervals of at least 33 ms. Apply limits in the Arduino firmware too. These command numbers do not prove the physical angle: calibrate the actual servo endpoints so the measured camera tilt stays within ±45° and neither servo reaches its stop. Begin with a much smaller range around neutral while checking the wiring.

No firmware was found in the supplied project folder, and the Arduino signal pins have not been confirmed. Original `Camera.cpp` and `Camera.exe` remain unchanged; the new executable has been compiled but not run against the hardware. Launch it with `Camera Tracker C++` as the working directory so it can find the existing model files, using the same OpenCV DLL environment as the original tracker. It still uses the existing COM5 port and 115200 baud settings. Confirm these match the connected Arduino. This guide does not assert that the existing firmware already enforces the limits.

Keep the servos powered to hold a position during use. Power loss, gear backlash or a slipping horn can still allow movement; this design is not a brake or a self-leveling mechanism.

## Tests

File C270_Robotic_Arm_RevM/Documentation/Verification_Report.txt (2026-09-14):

C270 ROBOTIC ARM REVISION M
Date: 2026-09-08

CAD RESULTS
68 recorded checks passed in CAD_and_Engineering_Results.json.
Four printable components are single valid solids.
All eight STEP exports re-import with the expected valid-solid counts.
27 x 15 mm rectangular opening is clear.
New 34 x 17 mm cap/holder screw pattern aligns and retains engagement material.
Original shaft-screw/tool paths and recessed horn mounting holes are open.
Servo ear, holder and cap interference checks pass.
Side servo cable ports and central rear USB opening are unobstructed.
Tilt motion checked every 5 degrees through -45 to +45 degrees.
Camera, clip, cradle, rotating horn and straight rear cable proxy checks pass.
Axial and radial separation also provide continuous camera/cradle clearance bounds.
The webcam body has 2.786 mm^3 intentional overlap at the flexible grip ribs.

CHANGE SUMMARY
Reprint arm, cap and cradle. Reuse the Revision L stability base.
The new base STL is SHA-256 identical to the Revision L base STL.
Arm ribbon thickness: 10 mm instead of 6 mm.
Cap opening: 27 x 15 mm instead of 22 x 15 mm.
Cap outer face: 42 x 26 mm with rear ear-retaining pads.
Camera orientation corrected to make the Y shaft change elevation.

ENGINEERING RESULTS
Estimated tilt demand with stated assumptions: 0.694 kg-cm.
The cited 1.8 kg-cm SG90 stall rating is not a continuous working rating.
Conservative sampled unanchored edge margin: 4.22 mm.
Conservative sampled restoring moment: 0.00638 N-m.
Decision: secure the base to a rigid work surface using all four M4 holes.
See Engineering_Check.md for inputs, formulas, assumptions and limitations.

SOFTWARE
Camera_RevM.cpp is a separate copy of the user's tracker source.
Command clamps changed from 0-180 to 45-135 on both axes.
Commands are limited to one degree per axis at intervals of at least 33 ms.
Camera_RevM.exe compiled and linked successfully with the existing g++/OpenCV setup.
The existing serial library emitted its pre-existing alloca-redefinition warning.
The new executable was not run against hardware. Firmware/pins are unconfirmed.
Original Camera.cpp and Camera.exe were not modified.

LIMITS
Actual hardware screw sizes, camera center of mass, printer fit, servo stiffness,
and flexible cable loops still require physical checks. No structural certification
or guarantee against arbitrary pulling force or loss of servo power is implied.
The CAD process printed REVISION M CAD CHECKS PASSED and all recorded checks passed,
but its runtime returned exit code 1 after completion, as on prior revisions.
The reason for that shutdown status is not established; the build is not described
as a clean process exit. The separate C++ compile returned exit code 0.

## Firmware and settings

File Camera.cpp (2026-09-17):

#include <opencv2/opencv.hpp>
#include <opencv2/dnn.hpp>
#include <iostream>
#include <vector>
#include <string>
#include <algorithm>
#include <cmath>
#include <thread>
#include <chrono>
#include <limits>
#include <sstream>
#include <iomanip>
#include <deque>
#include "serial/serial.h"

void sendServoCommand(
    serial::Serial& arduino,
    float panAngle,
    float tiltAngle,
    float& previousPanAngle,
    float& previousTiltAngle)
{
    // Send sub-degree commands. This removes the 1-degree staircase
    // that can make a hobby servo sit still and then suddenly jump.
    constexpr float minimumCommandChange = 0.05f;

    if (
        std::isfinite(previousPanAngle) &&
        std::isfinite(previousTiltAngle) &&
        std::abs(panAngle - previousPanAngle) <
            minimumCommandChange &&
        std::abs(tiltAngle - previousTiltAngle) <
            minimumCommandChange
    )
    {
        return;
    }

    std::ostringstream command;

    command
        << std::fixed
        << std::setprecision(2)
        << panAngle
        << ","
        << tiltAngle
        << "\n";

    arduino.write(command.str());

    previousPanAngle = panAngle;
    previousTiltAngle = tiltAngle;
}

struct AxisMPCConfig
{
    float tauSeconds;
    float commandGain;
    float delaySeconds;
    float pixelsPerDegree;
    float cameraEffectSign;

    float qError;
    float rControl;
    float sCommandChange;

    float maximumVelocity;
    float maximumAcceleration;

    int horizonSteps;
    float candidateStep;
};

struct AxisPredictiveState
{
    float modelVelocity = 0.0f;
    float targetImageVelocity = 0.0f;

    // Filtered raw image velocity. This is used only to determine whether
    // the detected face is genuinely stationary rather than reacting to
    // small YOLO / camera jitter.
    float measuredImageVelocity = 0.0f;

    float previousMeasuredError = 0.0f;
    float previousCommand = 0.0f;

    int delaySteps = 0;
    bool initialized = false;

    std::deque<float> delayQueue;
};

void resetAxisPredictiveState(
    AxisPredictiveState& state,
    float measuredError,
    const AxisMPCConfig& config,
    float nominalDt)
{
    state.modelVelocity = 0.0f;
    state.targetImageVelocity = 0.0f;
    state.measuredImageVelocity = 0.0f;
    state.previousMeasuredError = measuredError;
    state.previousCommand = 0.0f; 

    state.delaySteps =
        std::max(
            0,
            static_cast<int>(
                std::round(
                    config.delaySeconds /
                    nominalDt
                )
            )
        );

    state.delayQueue.clear();

    for (int i = 0; i < state.delaySteps; ++i)
        state.delayQueue.push_back(0.0f);

    state.initialized = true;
}

void advanceAxisObserver(
    AxisPredictiveState& state,
    float measuredError,
    float dt,
    const AxisMPCConfig& config,
    float nominalDt)
{
    if (!state.initialized)
    {
        resetAxisPredictiveState(
            state,
            measuredError,
            config,
            nominalDt
        );

        return;
    }

    float delayedCommand =
        state.previousCommand;

    if (state.delaySteps > 0)
    {
        if (state.delayQueue.empty())
            state.delayQueue.push_back(
                state.previousCommand
            );

        delayedCommand =
            state.delayQueue.front();

        state.delayQueue.pop_front();
    }

    float a =
        std::exp(
            -dt /
            std::max(
                config.tauSeconds,
                0.001f
            )
        );

    float b =
        config.commandGain *
        (1.0f - a);

    state.modelVelocity =
        a * state.modelVelocity +
        b * delayedCommand;

    float relativeImageVelocity =
        (
            measuredError -
            state.previousMeasuredError
        ) /
        std::max(dt, 0.001f);

    constexpr float measuredVelocityAlpha = 0.18f;

    state.measuredImageVelocity =
        measuredVelocityAlpha *
        relativeImageVelocity +
        (1.0f - measuredVelocityAlpha) *
        state.measuredImageVelocity;

    float cameraImageVelocity =
        config.cameraEffectSign *
        config.pixelsPerDegree *
        state.modelVelocity;

    float measuredTargetImageVelocity =
        relativeImageVelocity -
        cameraImageVelocity;

    measuredTargetImageVelocity =
        std::clamp(
            measuredTargetImageVelocity,
            -700.0f,
            700.0f
        );

    constexpr float observerAlpha = 0.14f;

    state.targetImageVelocity =
        observerAlpha *
        measuredTargetImageVelocity +
        (1.0f - observerAlpha) *
        state.targetImageVelocity;

    state.previousMeasuredError =
        measuredError;
}

void queueAxisCommand(
    AxisPredictiveState& state,
    float command)
{
    if (state.delaySteps > 0)
        state.delayQueue.push_back(command);

    state.previousCommand =
        command;
}

float solveAxisMPC(
    float measuredError,
    const AxisPredictiveState& state,
    const AxisMPCConfig& config,
    float dt)
{
    float bestCommand = 0.0f;
    float bestCost =
        std::numeric_limits<float>::infinity();

    float step =
        std::max(
            config.candidateStep,
            0.5f
        );

    for (
        float candidate =
            -config.maximumVelocity;
        candidate <=
            config.maximumVelocity +
            0.001f;
        candidate += step
    )
    {
        float simulatedError =
            measuredError;

        float simulatedVelocity =
            state.modelVelocity;

        float simulatedCommand =
            state.previousCommand;

        std::deque<float> simulatedDelay =
            state.delayQueue;

        float cost = 0.0f;

        for (
            int k = 0;
            k < config.horizonSteps;
            ++k
        )
        {
            float previousSimulatedCommand =
                simulatedCommand;

            float maximumCommandChange =
                config.maximumAcceleration *
                dt;

            simulatedCommand +=
                std::clamp(
                    candidate -
                        simulatedCommand,
                    -maximumCommandChange,
                    maximumCommandChange
                );

            float appliedCommand =
                simulatedCommand;

            if (state.delaySteps > 0)
            {
                simulatedDelay.push_back(
                    simulatedCommand
                );

                appliedCommand =
                    simulatedDelay.front();

                simulatedDelay.pop_front();
            }

            float a =
                std::exp(
                    -dt /
                    std::max(
                        config.tauSeconds,
                        0.001f
                    )
                );

            float b =
                config.commandGain *
                (1.0f - a);

            simulatedVelocity =
                a * simulatedVelocity +
                b * appliedCommand;

            float predictedErrorRate =
                state.targetImageVelocity +
                config.cameraEffectSign *
                config.pixelsPerDegree *
                simulatedVelocity;

            simulatedError +=
                predictedErrorRate *
                dt;

            float normalizedError =
                simulatedError /
                100.0f;

            float normalizedControl =
                simulatedCommand /
                std::max(
                    config.maximumVelocity,
                    0.1f
                );

            float normalizedCommandChange =
                (
                    simulatedCommand -
                    previousSimulatedCommand
                ) /
                std::max(
                    config.maximumVelocity,
                    0.1f
                );

            cost +=
                config.qError *
                    normalizedError *
                    normalizedError +
                config.rControl *
                    normalizedControl *
                    normalizedControl +
                config.sCommandChange *
                    normalizedCommandChange *
                    normalizedCommandChange;
        }

        float terminalError =
            simulatedError /
            100.0f;

        cost +=
            2.0f *
            config.qError *
            terminalError *
            terminalError;

        if (cost < bestCost)
        {
            bestCost = cost;
            bestCommand = candidate;
        }
    }

    return bestCommand;
}

int main()
{
    // CAMERA
    constexpr int cameraIndex = 1;

    cv::VideoCapture cap(cameraIndex, cv::CAP_DSHOW);

    if (!cap.isOpened())
    {
        std::cerr << "ERROR: Could not open webcam.\n";
        return 1;
    }

    cap.set(cv::CAP_PROP_FRAME_WIDTH, 1280);
    cap.set(cv::CAP_PROP_FRAME_HEIGHT, 720);
    cap.set(cv::CAP_PROP_BUFFERSIZE, 1);
    cap.set(cv::CAP_PROP_ZOOM, 0);

    std::cout << "Camera opened successfully.\n";

    // YOLO MODEL
    cv::dnn::Net net =
        cv::dnn::readNetFromONNX("Jerison_face.onnx");

    if (net.empty())
    {
        std::cerr << "ERROR: Could not load Jerison_face.onnx\n";
        return 1;
    }

    std::cout << "YOLO model loaded successfully.\n";

    // ARDUINO
    serial::Serial arduino;

    const std::string arduinoPort = "COM7";

    try
    {
        arduino.setPort(arduinoPort);
        arduino.setBaudrate(115200);

        serial::Timeout timeout =
            serial::Timeout::simpleTimeout(1000);

        arduino.setTimeout(timeout);
        arduino.open();
    }
    catch (const std::exception& error)
    {
        std::cerr
            << "Arduino connection error: "
            << error.what()
            << '\n';

        return 1;
    }

    if (!arduino.isOpen())
    {
        std::cerr << "ERROR: Arduino not connected.\n";
        return 1;
    }

    std::cout << "Arduino connected on " << arduinoPort << ".\n";

    std::this_thread::sleep_for(
        std::chrono::seconds(2)
    );

    // YOLO SETTINGS
    constexpr int inputWidth = 640;
    constexpr int inputHeight = 640;

    constexpr float confidenceThreshold = 0.50f;
    constexpr float nmsThreshold = 0.45f;

    // FACE POSITION SMOOTHING
    constexpr float smoothingAlpha = 0.16f;

    float smoothedFaceX = 0.0f;
    float smoothedFaceY = 0.0f;

    bool haveSmoothedTarget = false;

    // TRACKING HYSTERESIS
    // The axis starts moving only when the error is clearly outside center,
    // then stops only after it gets much closer to center.
    // This prevents stationary face noise from making the servos hunt.
    constexpr float panStartError = 45.0f;
    constexpr float panStopError = 18.0f;

    constexpr float tiltStartError = 40.0f;
    constexpr float tiltStopError = 15.0f;

    bool panTrackingActive = false;
    bool tiltTrackingActive = false;

    // STATIONARY HOLD
    // Once the face has remained near center and nearly motionless for a
    // few control cycles, freeze both axes. This prevents detector noise
    // and observer noise from causing tiny continuous servo corrections.
    bool stationaryHold = false;
    int stationaryHoldCounter = 0;

    constexpr int stationaryHoldFrames = 5; // about 0.25 s at 20 Hz

    constexpr float stationaryEnterErrorX = 28.0f;
    constexpr float stationaryEnterErrorY = 22.0f;

    constexpr float stationaryExitErrorX = 50.0f;
    constexpr float stationaryExitErrorY = 40.0f;

    constexpr float stationaryEnterVelocityX = 28.0f; // pixels / second
    constexpr float stationaryEnterVelocityY = 24.0f;

    constexpr float stationaryExitVelocityX = 70.0f;
    constexpr float stationaryExitVelocityY = 60.0f;

    // LEGACY PID CONSTANTS (AUTO uses predictive MPC)
    // Pan is tuned separately because this axis was sluggish/occasionally reversed.
    float panKp = 0.022f;
    float panKi = 0.0015f;
    float panKd = 0.0020f;

    float tiltKp = 0.024f;
    float tiltKi = 0.0020f;
    float tiltKd = 0.0030f;

    // LEGACY PID STATE (kept for reset/manual compatibility)
    float previousErrorX = 0.0f;
    float previousErrorY = 0.0f;

    float integralX = 0.0f;
    float integralY = 0.0f;

    float filteredDerivativeX = 0.0f;
    float filteredDerivativeY = 0.0f;

    bool pidInitialized = false;

    // DERIVATIVE FILTER
    constexpr float derivativeAlpha = 0.20f;

    // SERVO COMMANDS
    // panCommand / tiltCommand are the continuous PID targets.
    // panServoCommand / tiltServoCommand are what is actually sent.
    float panCommand = 90.0f;
    float tiltCommand = 90.0f;

    float panServoCommand = 90.0f;
    float tiltServoCommand = 90.0f;

    // SHARED DUAL-AXIS OUTPUT CLOCK
    // Pan keeps its 2-degree mechanical stepping.
    // Tilt keeps its smooth continuous PID command.
    // Both are sent together on the same 50 ms output tick.
    constexpr float panStepDegrees = 2.0f;
    constexpr int sharedOutputIntervalMs = 50;

    auto previousCoordinatedStepTime =
        std::chrono::steady_clock::now();

    // SERVO VELOCITIES
    float panVelocity = 0.0f;
    float tiltVelocity = 0.0f;

    // MOTION LIMITS
    constexpr float maximumVelocity = 18.0f;
    constexpr float maximumAcceleration = 45.0f;

    // SAFE SERVO LIMITS
    constexpr float panMinimum = 15.0f;
    constexpr float panMaximum = 165.0f;

    constexpr float tiltMinimum = 60.0f;
    constexpr float tiltMaximum = 120.0f;

    // CONTROL LOOP RATE
    constexpr int controlIntervalMs = 50;
    constexpr float nominalControlDt = 0.050f;

    auto previousControlTime =
        std::chrono::steady_clock::now();

    // IMAGE-PLANE PREDICTIVE MPC
    //
    // These are safe STARTING estimates, not measured plant parameters.
    // Tune tau, delay, and pixelsPerDegree later from logged experiments.
    AxisMPCConfig panMPC
    {
        0.24f,
        1.00f,
        0.10f,
        18.0f,
        +1.0f,
        1.00f,
        0.06f,
        0.28f,
        maximumVelocity,
        maximumAcceleration,
        10,
        3.0f
    };

    AxisMPCConfig tiltMPC
    {
        0.16f,
        1.00f,
        0.08f,
        18.0f,
        -1.0f,
        1.00f,
        0.07f,
        0.30f,
        maximumVelocity,
        maximumAcceleration,
        10,
        3.0f
    };

    AxisPredictiveState panPredictiveState;
    AxisPredictiveState tiltPredictiveState;

    // MANUAL MODE
    bool manualMode = false;

    constexpr float manualServoStep = 2.0f;

    // SMOOTH CENTER RESET
    bool smoothResetActive = false;
    constexpr float resetPanTarget = 90.0f;
    constexpr float resetTiltTarget = 90.0f;
    constexpr float resetSpeed = 10.0f; // degrees per second

    auto previousResetTime =
        std::chrono::steady_clock::now();

    // TARGET LOSS
    int lostFrames = 0;

    constexpr int resetAfterLostFrames = 10;

    // PREVIOUS SERVO COMMANDS
    float previousPanAngle =
        std::numeric_limits<float>::quiet_NaN();

    float previousTiltAngle =
        std::numeric_limits<float>::quiet_NaN();

    bool printedOutputShape = false;

    cv::Mat frame;

    while (true)
    {
        // READ CAMERA
        if (!cap.read(frame) || frame.empty())
        {
            std::cerr << "ERROR: Failed to read webcam frame.\n";
            break;
        }

        // LETTERBOX IMAGE
        float scale =
            std::min(
                static_cast<float>(inputWidth) /
                    static_cast<float>(frame.cols),

                static_cast<float>(inputHeight) /
                    static_cast<float>(frame.rows)
            );

        int resizedWidth =
            static_cast<int>(
                std::round(frame.cols * scale)
            );

        int resizedHeight =
            static_cast<int>(
                std::round(frame.rows * scale)
            );

        cv::Mat resized;

        cv::resize(
            frame,
            resized,
            cv::Size(resizedWidth, resizedHeight)
        );

        int padX =
            (inputWidth - resizedWidth) / 2;

        int padY =
            (inputHeight - resizedHeight) / 2;

        int padRight =
            inputWidth -
            resizedWidth -
            padX;

        int padBottom =
            inputHeight -
            resizedHeight -
            padY;

        cv::Mat letterboxed;

        cv::copyMakeBorder(
            resized,
            letterboxed,
            padY,
            padBottom,
            padX,
            padRight,
            cv::BORDER_CONSTANT,
            cv::Scalar(114, 114, 114)
        );

        // YOLO INPUT
        cv::Mat blob;

        cv::dnn::blobFromImage(
            letterboxed,
            blob,
            1.0 / 255.0,
            cv::Size(inputWidth, inputHeight),
            cv::Scalar(),
            true,
            false
        );

        net.setInput(blob);

        // RUN YOLO
        std::vector<cv::Mat> outputs;

        net.forward(
            outputs,
            net.getUnconnectedOutLayersNames()
        );

        if (outputs.empty())
        {
            std::cerr << "ERROR: YOLO returned no output.\n";
            break;
        }

        cv::Mat output = outputs[0];

        if (!printedOutputShape)
        {
            std::cout << "YOLO output: ";

            for (int i = 0; i < output.dims; i++)
            {
                std::cout << output.size[i];

                if (i < output.dims - 1)
                    std::cout << " x ";
            }

            std::cout << '\n';

            printedOutputShape = true;
        }

        if (output.dims != 3)
        {
            std::cerr << "ERROR: Unexpected YOLO output.\n";
            break;
        }

        // PARSE YOLO OUTPUT
        int dimensions = 0;
        int detections = 0;

        cv::Mat detectionData;

        if (output.size[1] < output.size[2])
        {
            dimensions = output.size[1];
            detections = output.size[2];

            cv::Mat raw(
                dimensions,
                detections,
                CV_32F,
                output.ptr<float>()
            );

            cv::transpose(raw, detectionData);
        }
        else
        {
            detections = output.size[1];
            dimensions = output.size[2];

            detectionData =
                cv::Mat(
                    detections,
                    dimensions,
                    CV_32F,
                    output.ptr<float>()
                );
        }

        if (dimensions != 5)
        {
            std::cerr
                << "ERROR: Expected 5 values per YOLO detection.\n";

            break;
        }

        // EXTRACT DETECTIONS
        std::vector<cv::Rect> boxes;
        std::vector<float> scores;

        for (int i = 0; i < detections; i++)
        {
            const float* data =
                detectionData.ptr<float>(i);

            float centerX = data[0];
            float centerY = data[1];
            float width = data[2];
            float height = data[3];
            float confidence = data[4];

            if (confidence < confidenceThreshold)
                continue;

            float leftLetterbox =
                centerX -
                width / 2.0f;

            float topLetterbox =
                centerY -
                height / 2.0f;

            float originalLeft =
                (leftLetterbox - padX) / scale;

            float originalTop =
                (topLetterbox - padY) / scale;

            float originalWidth =
                width / scale;

            float originalHeight =
                height / scale;

            cv::Rect box(
                static_cast<int>(
                    std::round(originalLeft)
                ),

                static_cast<int>(
                    std::round(originalTop)
                ),

                static_cast<int>(
                    std::round(originalWidth)
                ),

                static_cast<int>(
                    std::round(originalHeight)
                )
            );

            box &=
                cv::Rect(
                    0,
                    0,
                    frame.cols,
                    frame.rows
                );

            if (box.width <= 0 || box.height <= 0)
                continue;

            boxes.push_back(box);
            scores.push_back(confidence);
        }

        // NON MAXIMUM SUPPRESSION
        std::vector<int> indices;

        cv::dnn::NMSBoxes(
            boxes,
            scores,
            confidenceThreshold,
            nmsThreshold,
            indices
        );

        // FRAME CENTER
        int frameCenterX =
            frame.cols / 2;

        int frameCenterY =
            frame.rows / 2;

        cv::circle(
            frame,
            cv::Point(
                frameCenterX,
                frameCenterY
            ),
            6,
            cv::Scalar(255, 0, 0),
            -1
        );

        // DEAD ZONE
        cv::rectangle(
            frame,
            cv::Point(
                frameCenterX -
                    static_cast<int>(panStopError),

                frameCenterY -
                    static_cast<int>(tiltStopError)
            ),

            cv::Point(
                frameCenterX +
                    static_cast<int>(panStopError),

                frameCenterY +
                    static_cast<int>(tiltStopError)
            ),

            cv::Scalar(255, 255, 0),
            2
        );

        // TARGET SELECTION
        int targetIndex = -1;

        if (!indices.empty())
        {
            if (!haveSmoothedTarget)
            {
                float highestConfidence = -1.0f;
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

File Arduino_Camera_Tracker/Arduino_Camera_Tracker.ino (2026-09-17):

#include <Servo.h>

Servo panServo;
Servo tiltServo;

constexpr int PAN_PIN = 9;
constexpr int TILT_PIN = 10;

constexpr float PAN_MIN_DEG = 15.0f;
constexpr float PAN_MAX_DEG = 165.0f;
constexpr float TILT_MIN_DEG = 60.0f;
constexpr float TILT_MAX_DEG = 120.0f;

// Arduino Servo library's normal write(0..180) range.
// Using microseconds lets us keep sub-degree commands from the PC.
constexpr int SERVO_MIN_US = 544;
constexpr int SERVO_MAX_US = 2400;

float panAngle = 90.0f;
float tiltAngle = 90.0f;

int angleToMicroseconds(float angle)
{
    angle = constrain(angle, 0.0f, 180.0f);

    float fraction = angle / 180.0f;

    return static_cast<int>(
        round(
            SERVO_MIN_US +
            fraction *
            (SERVO_MAX_US - SERVO_MIN_US)
        )
    );
}

void writeServos()
{
    panServo.writeMicroseconds(
        angleToMicroseconds(panAngle)
    );

    tiltServo.writeMicroseconds(
        angleToMicroseconds(tiltAngle)
    );
}

void setup()
{
    Serial.begin(115200);
    Serial.setTimeout(20);

    panServo.attach(PAN_PIN);
    tiltServo.attach(TILT_PIN);

    writeServos();

    Serial.println("Ready");
}

void loop()
{
    if (Serial.available() <= 0)
        return;

    String command =
        Serial.readStringUntil('\n');

    command.trim();

    int commaPosition =
        command.indexOf(',');

    if (commaPosition < 0)
        return;

    float requestedPan =
        command
            .substring(0, commaPosition)
            .toFloat();

    float requestedTilt =
        command
            .substring(commaPosition + 1)
            .toFloat();

    panAngle =
        constrain(
            requestedPan,
            PAN_MIN_DEG,
            PAN_MAX_DEG
        );

    tiltAngle =
        constrain(
            requestedTilt,
            TILT_MIN_DEG,
            TILT_MAX_DEG
        );

    writeServos();
}

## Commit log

2026-09-14 Initial robotic webcam tracker
    [Arm.SLDPRT, Baseplate.SLDPRT, Bottom servo.SLDASM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]
2026-09-14 Remove outdated SolidWorks revisions
    [Baseplate.SLDPRT, Bottom servo.SLDASM, Pan_servo_case.SLDPRT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]
2026-09-14 Remove outdated loose SolidWorks part
    [Arm.SLDPRT]
2026-09-14 Remove outdated RevL CAD package
2026-09-16 Add custom YOLO training pipeline and PID face tracking
2026-09-17 Improve smooth pan tilt tracking and servo control
2026-09-17 feat: replace PID tracking with predictive MPC
    [Camera.cpp]
